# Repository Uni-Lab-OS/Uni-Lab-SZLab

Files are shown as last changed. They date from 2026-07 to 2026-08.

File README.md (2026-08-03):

# Uni-Lab SZLab Poly Studio

SZLab 聚合物工作站领域设备包。仓库根同时是 Python distribution root 和目标
Uni-Lab-OS workspace root；根目录只构建一个 distribution `szlab-poly-studio`，唯一常规
顶层 import package 是 `szlab_poly_studio`。

AI4C 已从本仓库迁出到同级的 `../Uni-Lab-AI4C/`，两边可以独立安装、测试、构建和发布。

## 目录合同

```text
Uni-Lab-SZLab/
├── pyproject.toml
├── szlab_poly_studio/
│   ├── devices/<device_id>/
│   │   ├── device.py
│   │   └── models/
│   ├── resources/
│   ├── workflows/
│   └── common/
├── deployment/
├── tests/
├── docs/
├── scripts/
└── migration/
```

没有 `packages/` 中间层，也没有独立的模型 entry-point 协议。设备、资源和工作流由各自装饰器
定义；模型元数据写在同一个 `@device` 或 `@resource` 上。设备专属资产放在
`devices/<device_id>/models/`，资源专属资产放在 `resources/<resource_id>/models/`，声明中
的 `entry` 相对装饰器所在 Python 文件解析。

当前仓库中的 2.5D 外形已按归属拆成各目录的 `models/shape.yml`。增加 3D 模型时，优先在
同一 `models/` 目录放置一个 Xacro 入口及其 `meshes/` 依赖，并在原装饰器的 `model` 中增加
`format: xacro`、`entry` 和 `macro`。同一 Xacro 默认同时作为 Web、kinematics 和 collision
来源；只有实际存在不同优化产物时才增加用途覆盖。

## 安装、检查和构建

在可运行 Uni-Lab-OS 的 Python 3.11 环境中：

```bash
python -m pip install -e . --no-deps
./scripts/check-package.sh
./scripts/build-package.sh
python -m pytest
```

wheel 输出到 `dist/`。`check-package.sh` 先编译完整 Catalog，再用 `--workspace` 做 OS
只读检查；`build-package.sh` 通过 package manager 构建并审计 clean wheel。设备、资源、工作流和
模型均由 Catalog 发现，Graph 是设备实例、物料拓扑、连接参数和本次激活选择的唯一权威来源。
仓库不再包含运行时 Profile。

Workflow 新代码遵循 Core 的
[`Workflow Python 写法规范`](https://github.com/Uni-Lab-OS/Uni-Lab-Core/blob/main/docs/guides/python-workflow-authoring-standard.md)。当前包含 13 个
Workflow；`s06_material.py` 是 Action 级 `ResourceSlot` 线性链参考实现。

## 本地联调

启动带 FE authoring API 的单进程测试 OS：

```bash
./scripts/start-authoring-os.sh
```

启动真实 runtime OS，或启动固定为测试模式的 OS：

```bash
./scripts/start-runtime-os.sh
./scripts/start-test-os.sh
```

OPC UA 仿真与 Edge 联调可直接使用 5 节点演示工作流
`szlab_poly_studio/workflows/robot_liquid_stirring_demo.py`；对应握手器启动命令见
[`docs/SZLAB_OPCUA_SIM_STARTUP_DEBUG.md`](docs/SZLAB_OPCUA_SIM_STARTUP_DEBUG.md)。

默认图中的直连 PLC 驱动均为 `auto_connect: false`。真机接入前必须单独核验 IP、NodeId、
账号、联锁、急停、物料占用和恢复语义。

SZLab 前端 E2E 截图见 [`docs/E2E_SCREENSHOTS.md`](docs/E2E_SCREENSHOTS.md)，迁移前 12 个历史
工作流的代码与 DAG 截图见
[`docs/ALL_WORKFLOW_SCREENSHOTS.md`](docs/ALL_WORKFLOW_SCREENSHOTS.md)。远端 OPC UA 仿真、
FE-OS 启动和排障命令见
[`docs/SZLAB_OPCUA_SIM_STARTUP_DEBUG.md`](docs/SZLAB_OPCUA_SIM_STARTUP_DEBUG.md)。全部工作流的
真机仿真结果见
[`docs/ALL_WORKFLOWS_LIVE_E2E_20260730.md`](docs/ALL_WORKFLOWS_LIVE_E2E_20260730.md)，动作与 PLC
日志规范见 [`docs/SZLAB_ACTION_LOGGING.md`](docs/SZLAB_ACTION_LOGGING.md)。

## 来源与许可

来源映射见 [`migration/manifest.yaml`](migration/manifest.yaml)，完整来源见 [`NOTICE`](NOTICE)。
上游设备驱动标记为 DP Technology Proprietary License；除非权利人明确授权，本仓库应保持
私有。详见 [`LICENSE`](LICENSE)。

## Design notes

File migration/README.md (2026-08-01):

# 迁移档案

本目录只保存从 `styxhuang/Uni-Lab-OS@d58a8c0` 提取的历史输入与映射证据，不作为运行时
配置源。

- `manifest.yaml` 是 11 个已提交 SZLab local UI preset、6 个 legacy JSON 工作流与当前 Python
  工作流之间的权威映射。
- `legacy/ui-presets`、`legacy/runtime-configs`、`legacy/workflows` 和 `legacy/plc_csv`
  保持原始内容，便于审计，因此可能包含已经失效的本机绝对路径或旧端点。
- 生产包只使用 `szlab_poly_studio/` 下的最新 CSV、Profile、设备实现和 Python 工作流。
- 未在当前工作区或定向浏览器/e2e 持久化位置发现可安全归属到该项目的活动
  `unilabos.workflowDraft`；因此迁移对象以已提交 preset/JSON 为准。

历史动作名 `auto-<method>` 已统一为 `<method>`。这是把工作流写成
`device("<device_id>").<method>(...)` 所必需的语法迁移，不改变相应设备方法。

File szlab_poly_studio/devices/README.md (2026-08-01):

# Device layout

Each device owns one directory named after its stable `@device(id=...)` value. The
driver entry is `device.py`; protocol tables, calibration-independent defaults,
and model assets stay beside it.

```text
devices/<device_id>/
├── device.py
├── models/
│   ├── device.xacro       # add when a 3D model is available
│   ├── meshes/
│   └── shape.yml         # optional 2.5D fallback
└── ...                    # sensors, CSV tables, and helpers
```

Model metadata belongs in the device's `@device(model={...})` declaration. Paths
are relative to `device.py`. A single Xacro entry is the default source for Web,
kinematics, and collision; declare an override only when a genuinely different
optimized asset exists.

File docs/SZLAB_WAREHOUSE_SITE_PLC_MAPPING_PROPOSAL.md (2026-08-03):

# SZLab Warehouse Site 与 PLC 映射确认稿

> 状态：PARTIALLY CONFIRMED / S2 已确认，S071 已按现有证据定案，S3/S11 产品类型仍待确认
> 日期：2026-08-03
> 目的：确认 Warehouse Site、Inventory Site、PLC 在位信号和机器人位置参数之间的映射。

## 1. 核对基线

运行语义基线采用 `origin/main@4682bb3`：

- `szlab_poly_studio/resources/warehouses.py`
- `szlab_poly_studio/resources/carriers/*.py`
- `deployment/graphs/szlab-local-debug.json`
- `szlab_poly_studio/devices/szlab_poly_plc/device.py`
- `szlab_poly_studio/devices/szlab_poly_plc/szlab_plc_0730.csv`

`origin/feat/szlab-material-display@28e6bc9` 的提交时间更新，包含新的 3D 资产和通用
`szlab_poly_beaker_warehouse` 类型，但它没有包含 `origin/main` 最新的启动图和 Workflow
修复。因此当前不存在一个同时包含两边最新内容的已提交分支。本稿使用 `origin/main` 的运行
语义，并交叉检查 material-display 分支的 Warehouse 几何和 Site 数量。

当前工作区的 Warehouse 定义与 `origin/main` 相同；本地启动图的 Warehouse、Site 和 110 个
容器物料与 `origin/main` 数量一致，主要差异是 registry class namespace 和其他设备节点。

### 1.1 启动图库存规模

| Warehouse instance | Site | `occupied_by` | 物料类型 |
|---|---:|---:|---|
| `s1_loading_buffer` | 6 | 6 | TIP box |
| `s2_tip_warehouse` | 6 | 6 | TIP box |
| `s3_unused_beaker` | 36 | 36 | 18×烧杯 + 18×500 mL 样品瓶 |
| `powder_container_warehouse` | 6 | 6 | 粉料容器 |
| `s10_liquid_reagent` | 20 | 20 | 100 mL 试剂瓶 |
| `s11_used_beaker` | 36 | 36 | 18×烧杯 + 18×500 mL 样品瓶 |
| **合计** | **110** | **110** | |

这个 JSON 是“全仓填充”的调试/展示库存。若真机现场不是全仓满载，不得把它原样作为生产
Inventory 初始事实；生产启动图必须按实际库存移除相应 `occupied_by` 和物料节点。

## 2. Site 的权威链路

### 2.1 Warehouse 初始化

Warehouse/ItemizedCarrier 初始化后已经具有：

- `_ordering`：Site label 到 holder 的有序映射；
- `child_locations`：Site 相对坐标；
- `child_size`：Site 尺寸；
- `sites`：当前 holder/occupant；
- `content_type`、`visible` 等序列化属性。

序列化到启动图后，这些信息位于 Warehouse node 的 `config.sites[]`。其中 `label` 是
Warehouse 内稳定的业务键，`occupied_by` 是启动时的逻辑占用关系。

### 2.2 Edge 本地查询

OS 启动后，Graph 只作为一次性输入；运行时权威是同一个可变 `ResourceTreeSet`。
`MaterialGraphCatalog` 把 Warehouse `config.sites[]` 投影为 Material Site：

- Site ID：由 graph identity、Warehouse node ID 和 Site label 确定性生成；
- owner：Warehouse 对应的 Material aggregate；
- occupant：由 `occupied_by` 解析为 Material UUID；
- geometry/content type：来自 Warehouse Site declaration。

前端通过 `GET /api/v1/materials?page=...` 获得 aggregate，现有 FE 会解析
`config.sites` 并展示安装位和占用数。对当前本地启动图实测可查询到 126 个 aggregate，
其中六个 Warehouse 合计 110 个 Site，110 个 Site 均有逻辑 occupant。

### 2.3 Backend Inventory

Backend 已有独立持久化 `Site` 实体，记录：

- `material_uuid`：拥有该 Site 的 Warehouse/Carrier Material；
- `name`、`sort_order`；
- `allowed_resource_template_uuids`；
- `occupied_material_uuid`；
- 几何位置和尺寸。

但当前缺少两段完整链路：

1. Deployment/Warehouse instance 激活时，将 Site declaration 幂等 materialize/upsert 为
   Backend Site rows；
2. 前端一次性查询 Backend 的 flat Site collection。当前 Backend 仅有
   `GET /api/v1/materials/{uuid}/sites`，FE 的 `getGraph()` 只读取 materials，不会逐个补取 Site。

目标链路应为：

```text
Warehouse Site declaration
  -> deployment activation/materialization
  -> Backend Material + Site rows
  -> GET /api/v1/sites（flat collection）
  -> FE 按 material_uuid 归组
```

Edge 本地的 `config.sites` 可保留为兼容投影，但不能成为与 Backend Site 并列的第二套可写
权威。PLC observation 也不能直接改写 `occupied_material_uuid`；它只提供 presence evidence。

## 3. SiteControlBinding 的归属

PLC 地址和机器人程序参数不是 Inventory Site 属性。它们属于 SZLab cell deployment 的
SiteControlBinding，使用 `(warehouse_instance_id, site_label)` 关联 Site declaration，materialize
后再解析到稳定 Site UUID。

每个 binding 至少包含：

```yaml
warehouse_instance_id: s3_unused_beaker
site_label: L1B1
observation:
  provider: szlab_poly_plc
  variable: 传感器状态_上位机[0].NO[6]
interaction:
  product_type: 1
  controller_position_key: 1-1
  controller_position_number: 1
```

运行时必须验证：

- Warehouse 的 Site 集合与 binding Site 集合完全相等或被显式标记为 `inventory_only`；
- 一个 PLC presence variable 只能绑定一个物理 Site；
- 一个 Site 的 sort order、PLC sensor order 和 robot position 是三个独立字段，禁止相互猜算；
- SiteControlBinding 解析为 RobotCommand 后，adapter 不再接收 Site、Material 或 SkillBinding。

## 4. 候选映射

### 4.1 S1 上料过渡仓：暂不绑定机器人/PLC Site

| Site labels | 数量 | 当前证据 | 结论 |
|---|---:|---|---|
| `L1C1..L1C3`, `L2C1..L2C3` | 6 | S01 robot action 只允许 position=1；`[3].NO[6]` 名义上是机械手产品检测，不是六个 Warehouse Site 的在位阵列 | 六个 Site 先标 `inventory_only`，不能猜成 S01 position 1..6 |

如果 S1 设备另有六个在位信号或上料索引表，需要补充现场 PLC 表后再绑定。

### 4.2 S2 TIP 仓：按 JSON Site 顺序映射 1..6（现场已确认）

顺序采用启动图 `config.sites[]` 和 `children[]` 的顺序：从低层到高层，每层从 C1 到 C2。
用户在 2026-08-03 确认该顺序；同时提供的两张 SZLab 3D 现场参考图显示 S2 为三层、每层
两位，图中由下到上分别标注 `T11/T12`、`T21/T22`、`T31/T32`，与启动图一致。

| Site | PLC/robot position | Presence variable |
|---|---:|---|
| `T11` | 1 | `传感器状态_上位机[0].NO[0]` |
| `T12` | 2 | `传感器状态_上位机[0].NO[1]` |
| `T21` | 3 | `传感器状态_上位机[0].NO[2]` |
| `T22` | 4 | `传感器状态_上位机[0].NO[3]` |
| `T31` | 5 | `传感器状态_上位机[0].NO[4]` |
| `T32` | 6 | `传感器状态_上位机[0].NO[5]` |

注意：最新 JSON 将 S2 描述为 3 层×2 位，但当前 `warehouses.py` 仍使用通用的 6×1×1
`warehouse_factory`。Warehouse 初始化实现必须改成与 JSON 和现场确认相同的 3×2 几何和
`T11..T32` label，避免代码初始化与启动图分叉。

本次确认确定了 Site label、层列关系、PLC/robot position 编号及候选 presence variable 的
静态映射。真机启用前仍须逐位放入/取出 TIP 盒，确认 `[0].NO[0..5]` 的实际变化与本表一一
对应；该动作属于映射验收，不再是编号设计决策。

### 4.3 S3 未使用容器仓：高置信度

Site label：

- `L{layer}B{column}`：500 mL 烧杯，`product_type=1`；
- `L{layer}A{column}`：500 mL 样品瓶，候选 `product_type=3`；
- `layer=1..3`，`column=1..6`。

映射规则：

```text
controller_position_key    = "{layer}-{column}"
controller_position_number = (layer - 1) * 6 + column
```

Presence variable：

- B 行按 `S3_UNUSED_BEAKER_SENSORS[controller_position_key]`；
- A 行按 `S3_UNUSED_SAMPLE_VIAL_SENSORS[controller_position_key]`。

边界样例：

| Site | type | key | number | Presence variable |
|---|---:|---|---:|---|
| `L1B1` | 1 | `1-1` | 1 | `[0].NO[6]` |
| `L3B6` | 1 | `3-6` | 18 | `[1].NO[7]` |
| `L1A1` | 3 | `1-1` | 1 | `[1].NO[8]` |
| `L3A6` | 3 | `3-6` | 18 | `[2].NO[9]` |

### 4.4 S071 固体粉桶堆栈机器人接口：位置采用紧凑编号 1..6

S07 在现场语义上应拆成三个概念：

- `powder_container_warehouse`：图中左侧 2 层×3 位的“固体粉桶堆栈”；
- `S071`：机械臂对该六位堆栈执行取/放粉罐时使用的 PLC/机器人子工位编号；
- `S07`：图中右侧带转盘的固体加料设备；其机器人产品交接接口在现有程序中称为 `S072`。

依据是：S071 动作明确叫“取/放粉罐”，读取粉桶堆栈六个 presence sensor，并写入
`S071取放料编号`；独立的 S07 设备动作则负责扫码、旋转到进料位和注粉。用户提供的现场
参考图也把左侧“固体粉桶堆栈”和右侧“S07 固体加料”标成两个物理对象。

Site label `L{layer}C{column}` 与 presence variable 的关系明确：

| Site | key | Presence variable | 采用 position | 当前代码 position |
|---|---|---|---:|---:|
| `L1C1` | `1-1` | `[3].NO[8]` | 1 | 1 |
| `L1C2` | `1-2` | `[3].NO[9]` | 2 | 2 |
| `L1C3` | `1-3` | `[3].NO[10]` | 3 | 3 |
| `L2C1` | `2-1` | `[3].NO[11]` | 4 | 7 |
| `L2C2` | `2-2` | `[3].NO[12]` | 5 | 8 |
| `L2C3` | `2-3` | `[3].NO[13]` | 6 | 9 |

采用值按 2 层×3 位紧凑编号。S07 专用传感器定义本身已经把六个粉桶位明确编号为 1..6；
当前 `robot_S07` 复用了服务于 S3/S11 每层 6 列的 `_slot_number()`，才导致第二层错误发送
7..9。这是跨工位复用编号公式造成的实现缺陷，不应上升为 Warehouse Site 语义。

实现时应由每个 SiteControlBinding 显式保存 `controller_position_number`，S071 不再调用通用
`_slot_number()`。真机启用前仍须以低速/单步模式验证 4、5、6 三个目标点，防止现场机器人
程序另有历史编号；若现场程序确实只接受 7..9，应修订部署 binding，而不是改变 Site label。

### 4.5 S10 试剂瓶仓：高置信度

Site label `R{row}C{column}`，`row=1..4`，`column=1..5`：

```text
controller_position_key    = "{row}-{column}"
controller_position_number = (row - 1) * 5 + column
presence_variable          = S10_LIQUID_REAGENT_SENSORS[key]
```

边界样例：

| Site | key | number | Presence variable |
|---|---|---:|---|
| `R1C1` | `1-1` | 1 | `[4].NO[12]` |
| `R1C5` | `1-5` | 5 | `[5].NO[0]` |
| `R2C1` | `2-1` | 6 | `[5].NO[1]` |
| `R4C5` | `4-5` | 20 | `[5].NO[15]` |

### 4.6 S11 使用后容器仓：高置信度

Site label、product type 和 position 规则与 S3 相同：

- B 行：500 mL 烧杯，`product_type=1`；
- A 行：500 mL 样品瓶，候选 `product_type=3`；
- number：`(layer - 1) * 6 + column`。

Presence variable 改用 S11 的两组：

| Site | type | key | number | Presence variable |
|---|---:|---|---:|---|
| `L1B1` | 1 | `1-1` | 1 | `[6].NO[0]` |
| `L3B6` | 1 | `3-6` | 18 | `[7].NO[1]` |
| `L1A1` | 3 | `1-1` | 1 | `[7].NO[2]` |
| `L3A6` | 3 | `3-6` | 18 | `[8].NO[3]` |

## 5. 映射覆盖结论

| 分类 | Site 数量 |
|---|---:|
| 已确认静态映射：S2 | 6 |
| 证据收敛后定案、待真机逐点验收：S071 | 6 |
| 高置信度 PLC binding：S3 + S10 + S11 | 92 |
| 无六位现场证据、暂定 inventory-only：S1 | 6 |
| **总计** | **110** |

候选配置可为 104 个 Site 生成互不重复的 PLC presence variable；S1 六个 Site 不生成
SiteControlBinding。

## 6. 确认后实施顺序

1. 将 material-display 的通用 beaker Warehouse/3D 资产合并到最新 main，生成一个真正统一的
   基线提交。
2. 修正 S2 Warehouse factory，使初始化结果、测试和 JSON 都是 `T11..T32`、3 层×2 位。
3. 新增 deployment-owned SiteControlBinding catalog；启动时与实际 Warehouse Site 集合做
   exact-set validation，缺项、重项或未知 Site 均拒绝启用机器人动作。
4. PLC stack observer 按 Site binding 重排 raw variables，向 OS 发布 Warehouse Site order 的
   observation array；传感器只提供 presence evidence。
5. Material Handling resolver 使用 Site UUID 查 binding，解析 Site Action 为 RobotCommand；
   PLC adapter 只接收 RobotCommand。
6. 增加 deployment Site materialization/upsert；Backend 提供 flat Site read collection，FE 一次
   查询并按 `material_uuid` 归组。
7. 保留两份启动数据：全仓 110 物料的 debug/display fixture，以及按现场真实占用生成的
   production inventory graph。

## 7. 现场确认状态

1. **已确认**：S2 的位置 1..6 依次对应 `T11,T12,T21,T22,T31,T32`。
2. **已按证据定案，待真机逐点验收**：S071 是固体粉桶堆栈的机器人接口，第二层采用紧凑
   编号 `4,5,6`；当前代码的 `7,8,9` 来自错误复用每层六列公式。
3. S3/S11 的 500 mL 样品瓶在机器人程序中是否确认为 `product_type=3`？

S2 可进入代码修正和逐位传感器验收；S071 可按 1..6 实现，但在逐点验收前不得开放自动
流程；S3/S11 的 product type 在确认前不接入真机执行路径。

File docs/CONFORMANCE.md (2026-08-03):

# SZLab 领域设备包一致性合同

## 仓库边界

- 仓库根是唯一 Python distribution root 和目标 OS workspace root；
- 根 `pyproject.toml` 的 distribution 是 `szlab-poly-studio`；
- 唯一常规顶层 import package 是 `szlab_poly_studio`；
- 不允许 `packages/` 中间层或第二个领域 import package；
- AI4C 由独立的同级仓库维护。

## 发现边界

- 顶层定义只来自 `@device`、`@resource`、`@workflow_definition`；
- 动作、状态和订阅装饰器归入所属设备；
- 模型由同一个设备/资源装饰器绑定；
- `deployment/`、`tests/`、`docs/`、`migration/` 不属于扫描根；
- 静态发现不得 import 驱动、实例化设备或连接硬件。
- Graph 是实例拓扑、连接参数与激活选择的唯一权威来源，不使用运行时 Profile。

## Workflow authoring 边界

- 新 Workflow 遵循 Core 的
  [`Workflow Python 写法规范`](https://github.com/Uni-Lab-OS/Uni-Lab-Core/blob/main/docs/guides/python-workflow-authoring-standard.md)；
- 新材料链必须从 Action 参数起使用 `ResourceSlot`，不能只靠 position/sample_id 和控制边推断；
- `szlab_poly_studio/workflows/s06_material.py` 是当前可发布的单工作流参考实现；
- `docs/examples/workflow_authoring/*_target.py` 只描述 C1 目标合同，不进入 `package.yaml`。

## 资产边界

- 设备资产位于 `devices/<device_id>/models/`；
- 资源资产位于 `resources/<resource_id>/models/`；
- 模型入口相对声明 Python 文件解析，并且必须位于 import package 内；
- wheel 必须携带 YAML、Xacro、URDF、mesh 和 texture 等完整依赖闭包；
- 运行日志、数据库、现场标定和凭据不得进入 wheel。

## 本地检查

```bash
python -m pip install -e . --no-deps
./scripts/check-package.sh
python -m pytest
./scripts/build-package.sh
```

`check-package.sh` 执行 `package inspect --path .` 与 `--workspace . --check_mode`；
`build-package.sh` 通过 package manager 构建并审计 clean wheel。自动测试同时验证 workspace /
clean-wheel Catalog 一致性。

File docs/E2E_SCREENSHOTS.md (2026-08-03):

# SZLab 最新前端 E2E 截图

本页聚焦 SZLab 物料视图和一个代表性工作流。全部 12 个生产工作流截图见
[`ALL_WORKFLOW_SCREENSHOTS.md`](ALL_WORKFLOW_SCREENSHOTS.md)。

截图由 `uni-lab-fe@d734337f63da832c11d704013be0d80f98681116`、
`deployment/graphs/szlab-local-debug.json` 和 FE-OS migration 后的单进程 OS 共同生成。浏览器视口为
1920×1200；当前复现流程通过 workspace Catalog 读取领域定义。

## Python 代码与节点画布

S04 机械臂—磁搅流程通过真实 `/api/v1/authoring/compile` 和
`/api/v1/workflows:validate` 接口，画布断言为 3 个节点、2 条控制边。

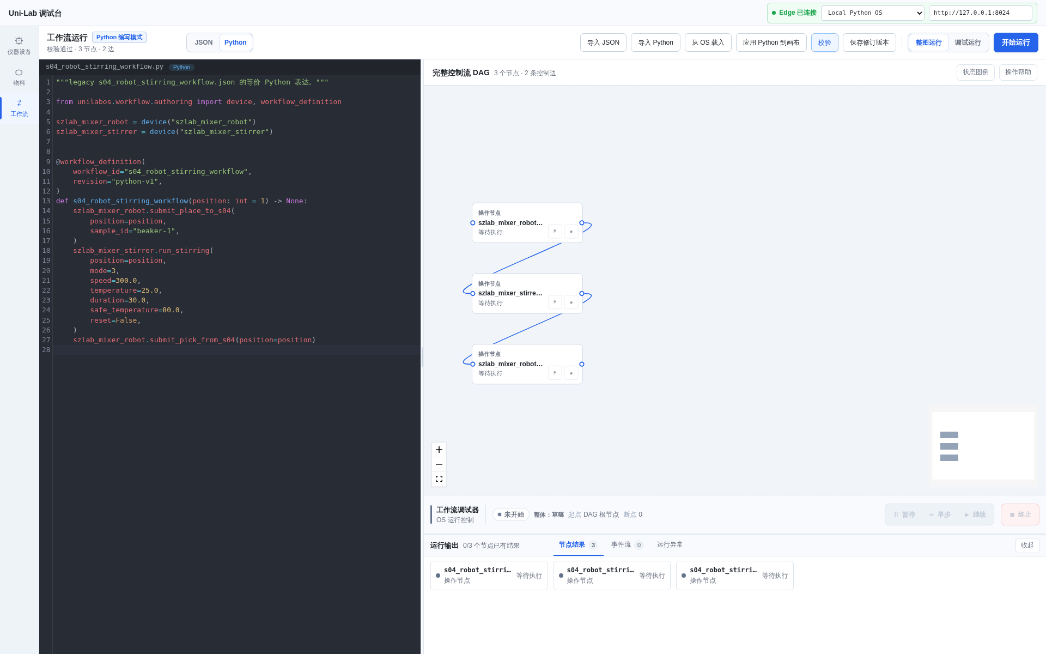
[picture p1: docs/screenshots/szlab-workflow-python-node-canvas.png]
SZLab Python 工作流与节点画布


## 2D 物料界面

2D 投影从 `/api/v1/materials` 加载 22 个 SZLab 聚合对象，不包含 AI4C 设备。

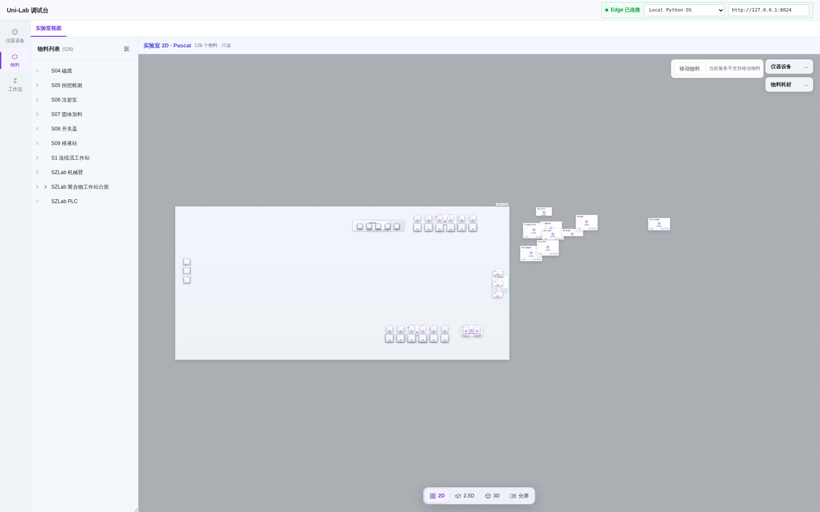
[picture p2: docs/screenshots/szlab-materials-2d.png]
SZLab 2D 物料界面


## 2.5D 物料界面

2.5D SVG 投影使用同一份 22 对象 Material Aggregate；截图选中了
`debug_beaker_500ml`，右侧 Inspector 展示其配置、世界坐标和 revision。

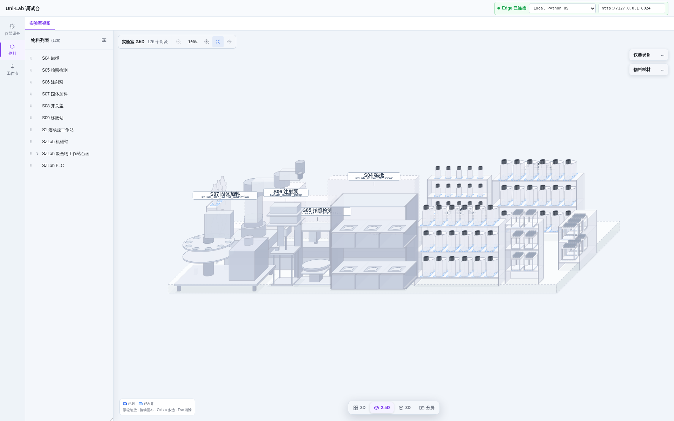
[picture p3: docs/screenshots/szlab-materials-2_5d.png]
SZLab 2.5D 物料界面


## 复现

先分别启动 SZLab 测试 OS 与最新前端：

```bash
UNILAB_PYTHON=/home/changjunhan/.micromamba/envs/unilab/bin/python \
  ./scripts/start-authoring-os.sh

cd ../uni-lab-fe
pnpm --filter @unilab/kernel-web preview --host 127.0.0.1 --port 4173
```

再从本仓库运行：

```bash
./scripts/capture-szlab-e2e.sh
```

机器可读结果保存在
[`screenshots/szlab-e2e-result.json`](screenshots/szlab-e2e-result.json)。
E2E 请求中的工作流编译、编写校验、Canonical 校验和 Material API 均为 200，未出现未预期的
浏览器错误。结果文件中旧设备页端点的历史兼容性警告不参与工作流与物料界面的通过判定。

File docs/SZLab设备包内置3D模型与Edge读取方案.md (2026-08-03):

# SZLab 设备包内置 3D 模型与 Edge 读取方案

## 结论

SZLab 模型应直接放在对应驱动目录的 `models/` 下，并由该驱动的 `@device(model=...)` 声明。
资源模型采用相同原则，放在 `resources/<resource_id>/models/` 并由 `@resource` 声明。仓库中
不再存在包级模型 provider 或总清单。

## 当前已落地结构

```text
szlab_poly_studio/
├── devices/
│   ├── szlab_mixer_robot/
│   │   ├── device.py
│   │   ├── robot_S01.py ... robot_S11.py
│   │   └── models/shape.yml
│   ├── szlab_mixer_pump/
│   │   ├── device.py
│   │   ├── sensors.py
│   │   ├── pump_nodes.csv
│   │   └── models/shape.yml
│   ├── szlab_mixer_stirrer/models/shape.yml
│   ├── szlab_mixer_photoshotting/models/shape.yml
│   └── szlab_s07_solid_addition/models/shape.yml
└── resources/
    ├── materials.py
    ├── warehouses.py
    └── <resource_id>/models/shape.yml
```

原全局 2.5D 外形数据已经无损拆到上述归属目录。每个资产由相应装饰器直接引用。仓库当前
没有提交真实 Xacro/mesh/GLB，所以不能声称 3D 闭环已完成；现在完成的是目录、绑定和打包
合同，以及已有 2.5D 资产的迁移。文件使用 `.yml` 是为了避开当前 OS 将设备子树内
`*.yaml` 误当旧式注册表的兼容缺陷；内容仍是标准 YAML，实际定位以装饰器 `entry` 为准。

## 机械臂加入真实 3D 模型后的目录

```text
szlab_poly_studio/devices/szlab_mixer_robot/
├── device.py
└── models/
    ├── device.xacro
    ├── meshes/
    │   ├── rail.stl
    │   ├── base.stl
    │   └── arm.dae
    ├── textures/
    ├── config/
    └── shape.yml
```

`device.py` 中的目标声明：

```python
@device(
    id="szlab_mixer_robot",
    display_name="SZLab Mixer 机器人任务",
    category=["robotic_arm"],
    model={
        "format": "xacro",
        "entry": "models/device.xacro",
        "macro": "szlab_mixer_robot",
        "shape": {
            "format": "unilab.shape/v1",
            "entry": "models/shape.yml",
        },
    },
)
class SzlabMixerRobotDevice:
    ...
```

一个 Xacro 就是默认的完整表示，不需要为 Web、kinematics 和 collision 重复三次。只有 Web
实际使用独立轻量 GLB，或 collision 使用独立简化体时，才写 `overrides`。

## `mesh_path` 的作用

`mesh_path` 很有用，但它是运行时注入的资产根，不是打包前替换的文本变量：

```xml
<xacro:macro name="szlab_mixer_robot" params="mesh_path prefix:=''">
  <link name="${prefix}rail">
    <visual>
      <geometry>
        <mesh filename="${mesh_path}/meshes/rail.stl"/>
      </geometry>
    </visual>
  </link>
</xacro:macro>
```

Edge 根据 Catalog 里的声明文件位置，把
`.../szlab_mixer_robot/models` 注入 `mesh_path`。这样 workspace、wheel 和缓存包只改变注入值，
Xacro 源文件完全相同。Web 获得的是 Edge 生成的资产 URL，不是这条服务器路径。

## Edge 目标读取方法

1. `unilab --workspace .` 读取根 `pyproject.toml`；
2. 定位唯一 import package `szlab_poly_studio`；
3. AST 递归扫描 `@device/@resource/@workflow_definition`；
4. 对每个模型按声明 Python 文件解析相对 `entry`；
5. 校验入口、include、mesh、texture、路径 containment 和 wheel package-data；
6. 把定义及资产闭包写进同一个 PackageCatalog；
7. Graph 选择设备后才 import 驱动；
8. 前端请求模型时，Edge 通过 Catalog 返回元数据和受控资产 URL；
9. Xacro consumer 以已校验模型目录作为 `mesh_path`。

发现模型不等于实例化设备，也不等于连接 PLC。AST 扫描和资产校验必须保持无副作用。

## 当前与目标的差距

SZLab 已完成根单包、驱动归位、外形共置、装饰器绑定和 package-data；OS 已提供
PackageCatalogCompiler、`--workspace`、资产 Source Adapter 和 Shape 资产读取。真实 3D
Edge/Web 闭环仍需等第一套真实 Xacro/mesh 到位后验收。

## 第一套真实模型建议

优先选择 `szlab_mixer_robot` 做垂直闭环，因为它同时覆盖 Xacro、mesh、关节、碰撞、
`mesh_path` 和 Web：

1. 提交可再分发的 Xacro 与 mesh；
2. 补充装饰器的 `format/entry/macro`；
3. 从 clean wheel 编译 Catalog；
4. 比较 workspace 与 wheel Catalog；
5. 启动 Edge，验证模型资产 URL；
6. 验证 Web、kinematics、collision 都来自同一默认 Xacro；
7. 再评估是否真的需要独立 Web GLB 或 collision override。

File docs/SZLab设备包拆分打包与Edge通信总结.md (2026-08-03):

# SZLab 设备包拆分、打包与 Edge 通信总结

## 1. 一般设备如何从 Uni-Lab-OS 分离为领域设备包

### 1.1 先确定边界

设备包应拥有设备驱动、动作、资源定义、工作流、协议表和模型资产；Uni-Lab-OS
保留通用装饰器、Registry、调度、通信抽象、PackageCatalog 编译和运行时。拆分时禁止把 OS
内部任意模块整段复制进设备包，只有确实属于领域设备且无法复用的适配器才进入 `common/`。

### 1.2 建立根单包仓库

```text
repository root = Python distribution root = OS workspace root
```

根 `pyproject.toml` 直接构建唯一 import package。SZLab 使用：

```text
distribution: szlab-poly-studio
import package: szlab_poly_studio
class namespace: community.szlab_poly_studio
```

一个包可以定义多个设备；设备身份来自各自的 `@device(id=...)`，不是来自 distribution 名。

### 1.3 迁移步骤

1. 将驱动类迁到 `devices/<device_id>/device.py`；
2. 保留 `@device`、`@action`、`@topic_config`、`@subscribe` 等装饰器；
3. 将资源工厂迁到 `resources/` 并保留 `@resource`；
4. 将 Python 工作流迁到 `workflows/` 并保留 `@workflow_definition`；
5. 将 CSV、JSON、Xacro、mesh、texture 放到拥有者目录；
6. 去除 OS 私有绝对 import、硬编码本机路径、凭据和运行数据；
7. 配置 package-data，构建 clean wheel 并验证静态发现结果；
8. 在 Graph 中写入实例拓扑和连接参数；只有 Graph 选中设备后，运行时才允许 import 和连接硬件。

AI4C 已作为同级 `Uni-Lab-AI4C/` 独立根单包，不再和 SZLab 组成 monorepo。

## 2. 设备包目录与包含的信息

SZLab 当前结构：

```text
Uni-Lab-SZLab/
├── pyproject.toml                 # distribution 身份、依赖、package-data
├── szlab_poly_studio/
│   ├── devices/<device_id>/
│   │   ├── device.py              # @device 与动作
│   │   ├── sensors.py             # 可选协议语义
│   │   ├── *.csv / *.json         # 协议表、静态参数
│   │   └── models/                # 设备专属模型闭包
│   ├── resources/                 # @resource、warehouse、deck、资源模型
│   ├── workflows/                 # @workflow_definition
│   ├── common/                    # 本包内部共享实现
│   └── __init__.py
├── deployment/graphs/             # 实例图；不属于装饰器扫描根
├── tests/                          # Catalog、Graph、工作流、资产和 wheel 测试
├── scripts/                        # build/check/start 辅助入口
├── docs/
└── migration/                      # 可审计历史输入，不参与运行时发现
```

不同层次的信息含义：

- `@device/@resource/@workflow_definition`：稳定类型身份和静态能力；
- 从属装饰器：设备的动作、状态、订阅和调度属性；
- Graph：本次部署的实例 ID、位置、连接参数和选择结果；
- `models/`：随设备/资源类型发布的可移植模型，不保存现场标定；
- runtime：日志、数据库、缓存，不进入 wheel 和 Git。

## 3. 设备包如何与 Uni-Lab-OS Edge 通信

### 3.1 发现与运行分离

目标启动方式：

```bash
unilab --workspace . -g deployment/graphs/szlab-local-debug.json
```

OS 读取根 `pyproject.toml`，AST 扫描唯一 import package，编译统一 PackageCatalog。这个阶段不
import 驱动、不实例化设备、不连接 PLC。Graph 选择本次运行需要的实例；选中后才加载对应
Python 类。

仓库检查入口为：

```bash
python -m unilabos.app.main package inspect --path .
unilab --workspace . --check_mode
```

2.5D 模型使用显式绑定的 `models/shape.yml`，避免兼容加载器把设备子树内的 `*.yaml`
误判成旧注册表。目录已经符合 workspace 合同，但不能把兼容命令当成最终 package manager。

### 3.2 Edge 内的通信层次

```text
设备包装饰器/驱动
        │
        ▼
Registry + PackageCatalog
        │
        ├── ROS device action / topic / subscription
        ├── local bridge authoring/runtime API
        └── Edge asset API（模型）
        │
        ▼
PLC / HTTP 设备 / 前端 / 调度器
```

SZLab 的 PLC 结构是“一条实际 PLC 连接 + 多个业务设备”：

- `szlab_poly_plc` 拥有 OPC UA 连接和通用读写动作；
- robot、S04-S09 等业务设备通过 `PLCActionGateway` 调用 PLC 设备动作；
- 业务设备不各自建立第二条 OPC UA 连接；
- Graph 中用 `plc_device_id: szlab_poly_plc` 绑定实例；
- 测试图默认 `auto_connect: false`。

### 3.3 工作流与 Graph

Python 工作流通过 `device("instance_id").action(...)` 描述调用，由 OS AST 编译成 Canonical
workflow；不使用 `eval/exec`。工作流声明随 Catalog 交付，Graph 决定具体实例、拓扑与连接
参数；local bridge 与 Edge 消费同一份 PackageCatalog，不维护另一套扫描器。

### 3.4 模型通信

模型通过 `@device/@resource(model=...)` 进入 Catalog。Edge 根据声明文件解析相对路径、校验
资产闭包并返回受控 URL；Xacro 的 `mesh_path` 由 Edge 注入。详细规范见
[`设备包3D模型存储规范.md`](设备包3D模型存储规范.md)。

## 4. 验证命令

```bash
python -m pip install -e . --no-deps
./scripts/check-package.sh
python -m pytest
./scripts/build-package.sh
```

验收至少覆盖：唯一根包、Catalog 发现数量、Graph 引用闭合、工作流编译、模型相对路径、wheel
资产闭包、workspace/clean-wheel Catalog 一致、无跨包 import、默认不连硬件。

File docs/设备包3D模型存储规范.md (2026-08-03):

# Uni-Lab 领域设备包 3D 模型存储规范

## 1. 目标与适用范围

本规范定义设备或资源的 3D/2.5D 模型如何随领域设备包一起安装、发现、校验和读取。目标是：

- 引用一个设备包时，同时获得驱动、动作、资源、工作流和模型；
- workspace、editable install、wheel 和远端缓存包使用同一套相对路径语义；
- 模型身份只绑定在 `@device` 或 `@resource`，不再维护包级第二份发现协议；
- 设备专属资产与驱动共同演进，移动设备目录时能整体迁移；
- 未选中的设备可以被静态发现，但不会因此实例化、连接硬件或执行 Xacro。

本文中的“必须”“禁止”“推荐”分别表示规范性要求、不可接受做法和默认选择。

## 2. 仓库与 Python 包边界

领域仓库根必须同时是 Python distribution root 和 OS workspace root：

```text
Uni-Lab-SZLab/
├── pyproject.toml
├── szlab_poly_studio/              # 唯一顶层 import package
│   ├── devices/
│   ├── resources/
│   ├── workflows/
│   └── common/
├── deployment/
├── tests/
├── docs/
├── scripts/
└── migration/
```

禁止增加 `packages/` 中间层。一个 import package 可以包含任意多个设备、资源和工作流；
“一个 distribution”不等于“一个设备”。

## 3. 资产放置位置

### 3.1 设备专属模型

```text
<import_package>/devices/<device_id>/
├── device.py
├── models/
│   ├── device.xacro
│   ├── meshes/
│   │   ├── base.stl
│   │   └── arm.dae
│   ├── textures/
│   ├── config/
│   └── shape.yml
└── ...
```

`<device_id>` 必须与 `@device(id="...")` 的稳定机器 ID 一致。设备模型禁止放到仓库根的共享
`models/`，也不应塞进 `scripts/`、`deployment/` 或运行时数据目录。

### 3.2 资源专属模型

```text
<import_package>/resources/<resource_id>/models/
├── resource.xacro
├── meshes/
├── textures/
└── shape.yml
```

资源 ID 必须与 `@resource(id="...")` 一致。两个资源确实使用同一几何时，可以在构建阶段从
一个明确的源生成两份闭包，或者等待 Catalog schema 提供受控的包内共享引用；禁止使用逃出
Python 包根的 `../../..` 路径。

## 4. 装饰器是唯一模型绑定点

### 4.1 Xacro 默认写法

```python
@device(
    id="szlab_mixer_robot",
    display_name="SZLab 搬运机械臂",
    category=["robotic_arm", "material_transport"],
    model={
        "format": "xacro",
        "entry": "models/device.xacro",
        "macro": "szlab_mixer_robot",
    },
)
class SzlabMixerRobotDevice:
    ...
```

`entry` 相对声明该装饰器的 `device.py` 解析，而不是相对进程当前目录、仓库根或 OS 安装目录。

当 `format == "xacro"` 时，这一个入口默认同时表达：

- Web 可视化的几何与关节树；
- kinematics 使用的 link/joint 结构；
- collision 使用的碰撞几何。

因此禁止为了形式完整，把同一个 Xacro 重复写成三份 `web/kinematics/collision` 配置。只有
确实生成了不同资产时才增加覆盖，例如 Web 使用轻量 GLB、碰撞使用凸包 URDF：

```python
model={
    "format": "xacro",
    "entry": "models/device.xacro",
    "macro": "szlab_mixer_robot",
    "overrides": {
        "web": {"format": "glb", "entry": "models/web/device.glb"},
        "collision": {"format": "urdf", "entry": "models/collision/device.urdf"},
    },
}
```

### 4.2 2.5D 外形

没有真实 3D 模型时，可以绑定轻量外形作为前端回退：

```python
model={
    "shape": {
        "format": "unilab.shape/v1",
        "entry": "models/shape.yml",
    },
}
```

之后加入 Xacro 时，在同一个 `model` 字典增加 `format/entry/macro`，保留 `shape` 作为低带宽
或加载失败时的回退。不要恢复全包外形清单。

本规范把轻量外形文件统一命名为 `shape.yml`。`.yml` 是标准 YAML，模型由装饰器中的显式
`entry` 定位，不依赖扩展名发现。Catalog 同时接受 `.yml` 和 `.yaml`，但包内应保持一种命名，
避免无意义的格式分叉。

## 5. Xacro 与 `mesh_path`

推荐继续使用 Xacro，尤其是有关节、宏参数、多个 mesh、碰撞体或 MoveIt 配置的设备。静态、
无关节且只服务浏览器的资源可以直接用 GLB；简单刚体也可用 URDF。

Xacro 中可以保留 `mesh_path` 参数：

```xml
<xacro:macro name="szlab_mixer_robot" params="mesh_path prefix:=''">
  <mesh filename="${mesh_path}/meshes/base.stl"/>
</xacro:macro>
```

但 `mesh_path` 的值必须由 Edge 的资产 Source Adapter 注入：

- workspace：注入 `device.py` 同级的 `models/` 绝对路径；
- installed distribution：通过 `importlib.resources` 定位 wheel 中的 `models/`；
- cached archive：注入校验、解包后的只读缓存资产根；
- Web：Edge 返回受控资产 URL 根，不向浏览器泄露服务器绝对路径。

用户不需要手改 Xacro 的本机绝对路径，也不需要在打包前批量替换路径。构建脚本只负责校验
闭包和生成 Catalog，不应重写源文件。

## 6. 模型目录应包含什么

按需包含：

- 主入口：`device.xacro`、`resource.xacro`、`.urdf` 或 `.glb`；
- 几何：STL、DAE、OBJ/MTL、GLTF/GLB；
- 贴图：PNG/JPEG 等；
- 运动学/控制配置：仅在设备确实需要时放入 `config/`；
- 2.5D 回退：`shape.yml`；
- 资产许可证和来源说明：第三方 CAD/mesh 必须可追溯。

生产示教点、现场标定结果、密钥、IP、操作者和运行日志禁止进入通用 wheel。机器人点位合同可
随包，现场 pose 与 calibration revision 应由部署侧权威存储维护。

## 7. 打包要求

`pyproject.toml` 必须包含所有资产类型：

```toml
[tool.setuptools.package-data]
szlab_poly_studio = [
  "**/*.yaml", "**/*.yml", "**/*.xacro", "**/*.urdf",
  "**/*.stl", "**/*.dae", "**/*.obj", "**/*.mtl",
  "**/*.gltf", "**/*.glb", "**/*.png", "**/*.jpg", "**/*.jpeg",
]
```

构建检查必须在干净 wheel 中验证：

1. 每个装饰器 `model.entry` 是静态字符串；
2. 路径相对声明文件解析并位于 import package 内；
3. 入口和它引用的 include、mesh、texture 均存在；
4. symlink 不逃出资产根；
5. wheel 安装后仍能得到同一个资产闭包；
6. workspace Catalog 与 clean-wheel Catalog 一致。

## 8. Edge 读取流程

目标 OS 的读取链路是：

```text
workspace / installed wheel / cached archive
                │
                ▼
        PackageCatalogCompiler
        ├── AST 读取装饰器元数据
        ├── 解析声明文件位置
        ├── 校验 model.entry 与资产闭包
        └── 生成统一 PackageCatalog
                │
        ┌───────┴────────┐
        ▼                ▼
  Registry/Runtime   Edge asset API
                          │
                          ▼
                     Web / Xacro consumer
```

发现阶段只读 AST 和静态资产，不 import 驱动、不执行 Xacro、不实例化设备。Graph 选中
某个设备后，运行时才允许 import 驱动；Web 请求模型时，Edge 再通过 Catalog 中的声明位置读取
已校验资产。

## 9. 安全与版本规则

- 拒绝绝对路径、路径逃逸和资产根外 symlink；
- 不根据设备名称猜文件路径；
- 不允许浏览器直接读取服务器文件系统；
- 模型变化随 distribution 版本发布，Catalog 记录版本和 digest；
- 超大 CAD 源文件是否进包由许可证和体积策略决定，运行必需的派生资产必须进入 wheel；
- 模型解析失败应产生明确诊断，不得静默连接硬件或使用错误设备模型。

## 10. 提交检查清单

- [ ] 模型位于对应设备/资源的 `models/`；
- [ ] `@device/@resource` 直接绑定模型；
- [ ] Xacro 只声明一次默认入口；
- [ ] `mesh_path` 由 Edge 注入，无本机绝对路径；
- [ ] package-data 覆盖完整资产类型；
- [ ] workspace 与 wheel 中的相对路径一致；
- [ ] 未携带现场点位、密钥或运行数据；
- [ ] 许可证和来源可追溯；
- [ ] 不存在包级第二套模型发现配置。

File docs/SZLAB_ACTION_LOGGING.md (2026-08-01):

# SZLab 动作与 PLC 等待日志

SZLab 设备动作默认在 Edge 日志中输出结构化、可检索的调试信息。该功能只修改
Uni-Lab-SZLab 设备包，不修改 Uni-Lab-OS。

## 日志标记

| 标记 | 内容 |
| --- | --- |
| `SZLAB-ACTION` | 每个 `@action` 的动作名称、输入参数、耗时、结果或失败原因 |
| `SZLAB-STEP` | 设备内部业务步骤，例如等待烧杯、允许加工、机器人握手或参数清零 |
| `SZLAB-PLC-CALL` | 业务设备通过唯一 `szlab_poly_plc` 发起的跨设备调用 |
| `SZLAB-PLC-WAIT` | 等待变量、期望值、实际值变化、持续等待、成功或超时 |
| `SZLAB-PLC-WRITE` | 写入变量、值、NodeId、尝试次数、耗时和失败异常 |
| `SZLAB-PLC-READ` | 读取失败及其异常；成功读取仅在 DEBUG 级别记录，避免属性轮询刷屏 |
| `SZLAB-HTTP` | S1 HTTP 动作等待的接口、超时、响应状态和网络异常 |

密码、Token、Secret、Authorization 等字段会显示为 `***`。长列表和字典会截断，
防止单条日志过大。

## 示例

```text
[SZLAB-ACTION] START trace=38a55f16b2 action=SzlabMixerPumpDevice.run_solvent_addition params={'pump': 1, 'volume': 8, ...}
[SZLAB-STEP] WAIT trace=38a55f16b2 action=SzlabMixerPumpDevice.run_solvent_addition description=等待 S06 允许加工 variable=S06允许加工 expected=True timeout=300.000s
[SZLAB-PLC-CALL] START trace=38a55f16b2 action=SzlabMixerPumpDevice.run_solvent_addition plc_device=szlab_poly_plc operation=wait_variable_equal ...
[SZLAB-PLC-WAIT] OBSERVED trace=- action=- variable=S06允许加工 node_id=ns=4;s=上位机通讯|S06允许加工 expected=True actual=False elapsed=0.081s
[SZLAB-PLC-WAIT] SUCCESS trace=- action=- variable=S06允许加工 node_id=ns=4;s=上位机通讯|S06允许加工 expected=True actual=True elapsed=5.132s
[SZLAB-PLC-WRITE] START trace=- action=- variable=S06工艺选择 node_id=ns=4;s=上位机通讯|S06工艺选择 value=1 attempts=3
[SZLAB-PLC-WRITE] SUCCESS trace=- action=- variable=S06工艺选择 node_id=ns=4;s=上位机通讯|S06工艺选择 value=1 attempt=1/3 elapsed=0.047s
[SZLAB-ACTION] SUCCESS trace=38a55f16b2 action=SzlabMixerPumpDevice.run_solvent_addition elapsed=18.245s result='S06 泵 1 加液流程完成'
```

如果等待失败，会包含最后一次实际值：

```text
[SZLAB-PLC-WAIT] TIMEOUT ... variable=S06加工完成 expected=True last_actual=False elapsed=300.041s
[SZLAB-ACTION] FAIL ... reason='S06 加工完成等待超时'
```

如果写入失败，会包含变量、写入值、NodeId、重试次数和原始异常：

```text
[SZLAB-PLC-WRITE] FAIL ... variable=S06参数写入完成 ... value=True attempt=3/3 cause=TimeoutError: timed out
```

`trace` 用于关联同一业务动作的 `SZLAB-ACTION`、`SZLAB-STEP` 和
`SZLAB-PLC-CALL`。统一 PLC 设备在独立 ROS 执行线程中处理实际 OPC UA 请求，因此底层
`SZLAB-PLC-WAIT/WRITE/READ` 可能显示 `trace=-`；此时按变量名、操作名和相邻时间定位。

## 实时查看

后台启动 Edge 时：

```bash
cd /home/changjunhan/Uni-Lab-Core/Uni-Lab-SZLab

tail -f runtime/ideawit-e2e/logs/edge.log \
  | rg --line-buffered 'SZLAB-(ACTION|STEP|PLC-CALL|PLC-WAIT|PLC-WRITE|PLC-READ|HTTP)'
```

查看某次动作的完整链路：

```bash
rg 'trace=38a55f16b2|S06加工完成|S06工艺选择' \
  runtime/ideawit-e2e/logs/edge.log
```

只看失败：

```bash
rg 'SZLAB-.*(FAIL|TIMEOUT|ERROR)' \
  runtime/ideawit-e2e/logs/edge.log
```

交互式启动 Edge 时这些日志会同时直接显示在终端。

## 等待日志频率

等待开始时打印一次；实际值变化时打印一次；值没有变化时每 10 秒打印一次
`STILL`；成功或超时时再打印一次。普通成功读取保持 DEBUG 级别，心跳写入也保持
DEBUG 级别，避免掩盖真正的动作日志。

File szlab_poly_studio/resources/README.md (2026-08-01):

# Resource layout

Resource factories live in this package and bind their assets directly through
`@resource(model={...})`. Resource-owned files use the stable resource ID:

```text
resources/<resource_id>/models/
├── resource.xacro         # add when a 3D model is available
├── meshes/
└── shape.yml             # optional 2.5D fallback
```

Model paths are relative to the Python file containing the decorator. There is no
package-wide model provider or model manifest.

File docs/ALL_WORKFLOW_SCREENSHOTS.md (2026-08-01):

# 全部生产工作流 E2E 截图

总计 12 个 SZLab 生产 Python 工作流。每个工作流都经过：

1. Python 源码直接提交 `/api/v1/authoring/compile`；
2. 最新 `uni-lab-fe` Python 编辑器重新载入源码；
3. 点击“编译 Python”；
4. 点击“校验”并通过 `/api/v1/workflows:validate`；
5. 核对真实节点数与控制边数后截取代码和完整 DAG。

机器可读结果见
[`screenshots/all-workflows-e2e-result.json`](screenshots/all-workflows-e2e-result.json)。

## SZLab

### 1. S04 磁搅单工位

`szlab_magnetic_stirring_workflow`：1 节点、0 边。

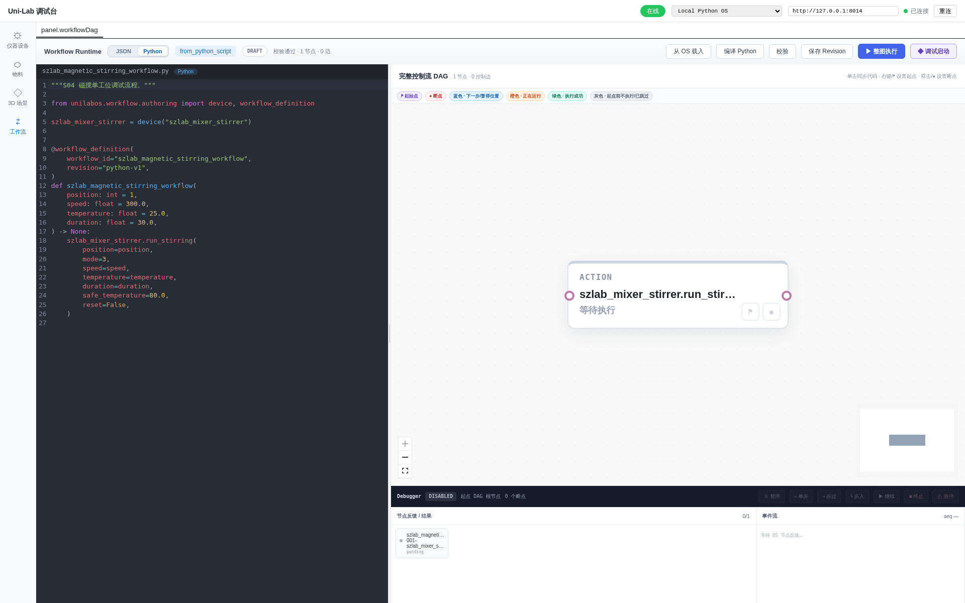
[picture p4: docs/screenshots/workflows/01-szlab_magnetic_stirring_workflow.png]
S04 磁搅单工位


### 2. S05 拍照检测

`szlab_photoshotting_workflow`：1 节点、0 边。

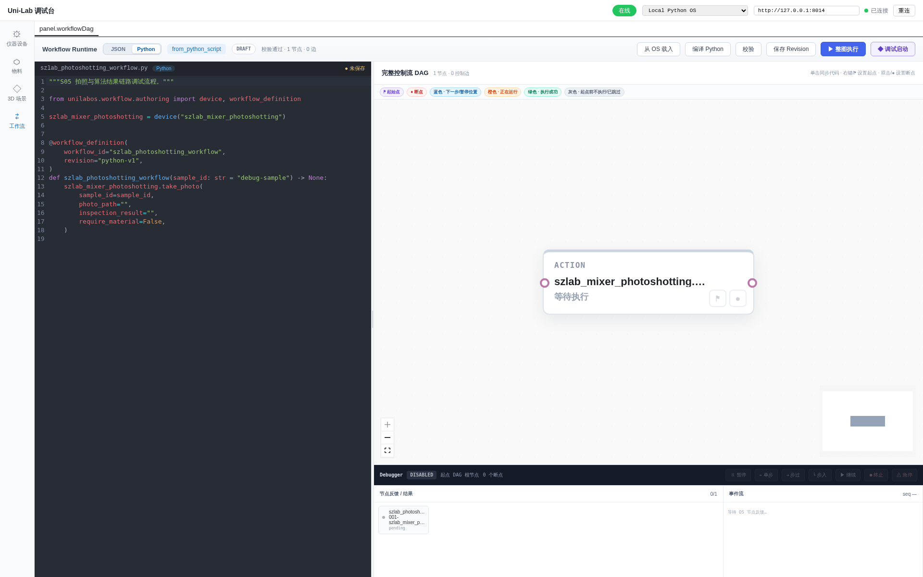
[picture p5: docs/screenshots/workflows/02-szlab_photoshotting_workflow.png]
S05 拍照检测


### 3. 机械臂 S04 取放

`szlab_robot_action_workflow`：2 节点、1 边。

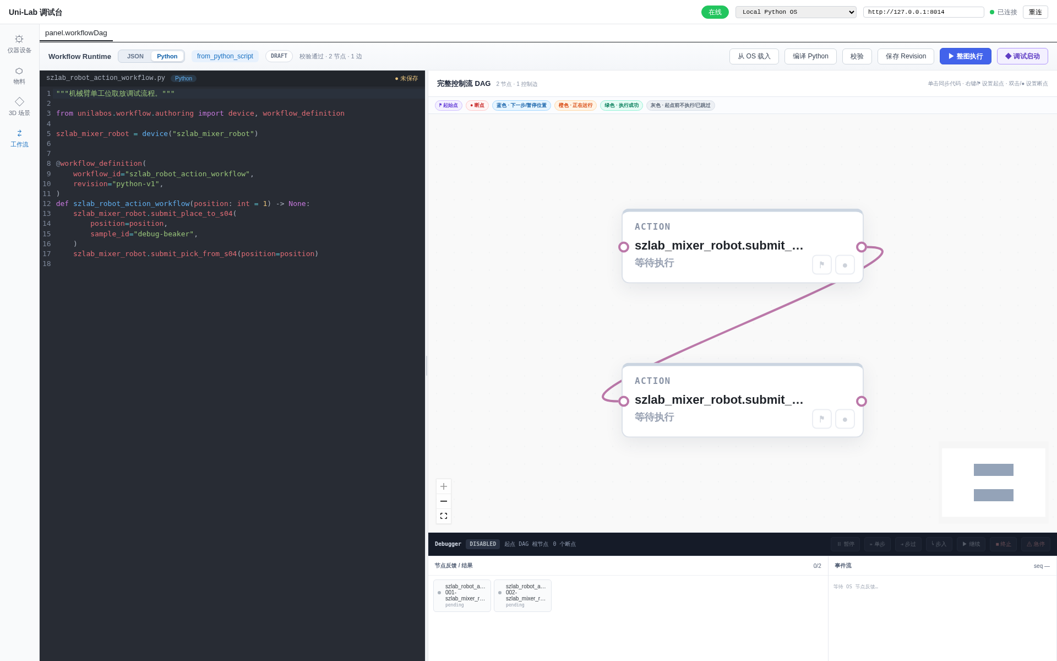
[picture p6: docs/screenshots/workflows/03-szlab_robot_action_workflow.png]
机械臂 S04 取放


### 4. S04 机械臂—磁搅

`s04_robot_stirring_workflow`：3 节点、2 边。

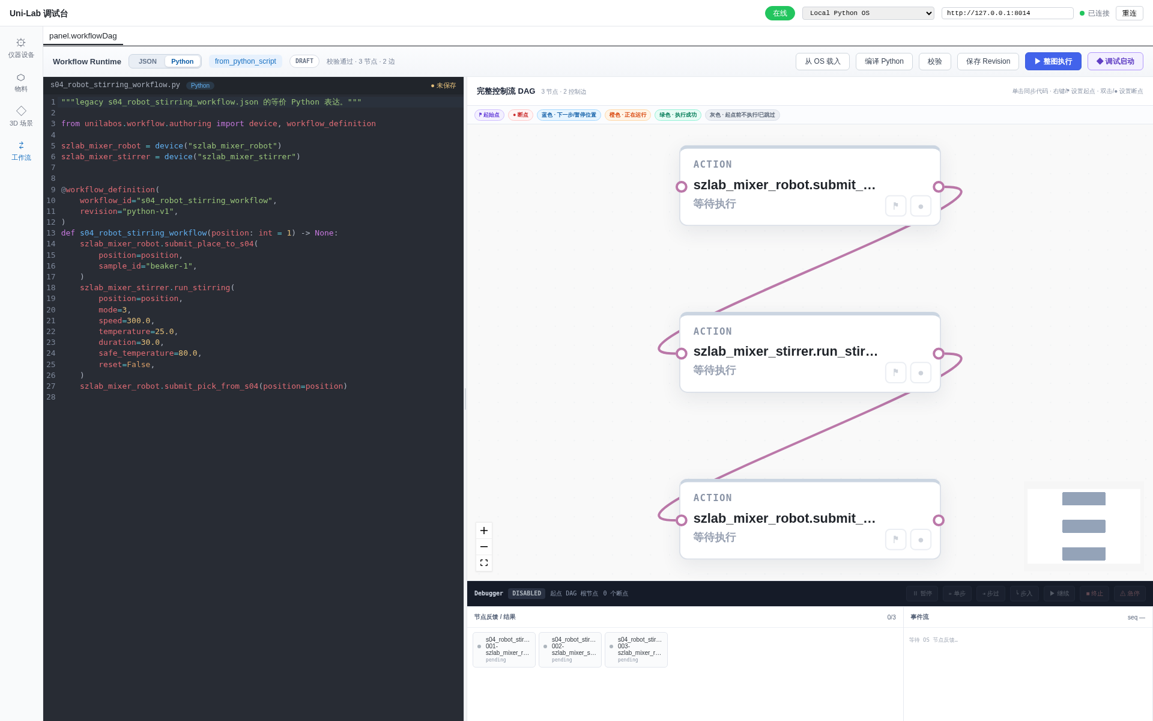
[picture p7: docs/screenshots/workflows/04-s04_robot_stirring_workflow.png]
S04 机械臂—磁搅


### 5. S06 机械臂—加液

`s06_robot_workflow`：3 节点、2 边。

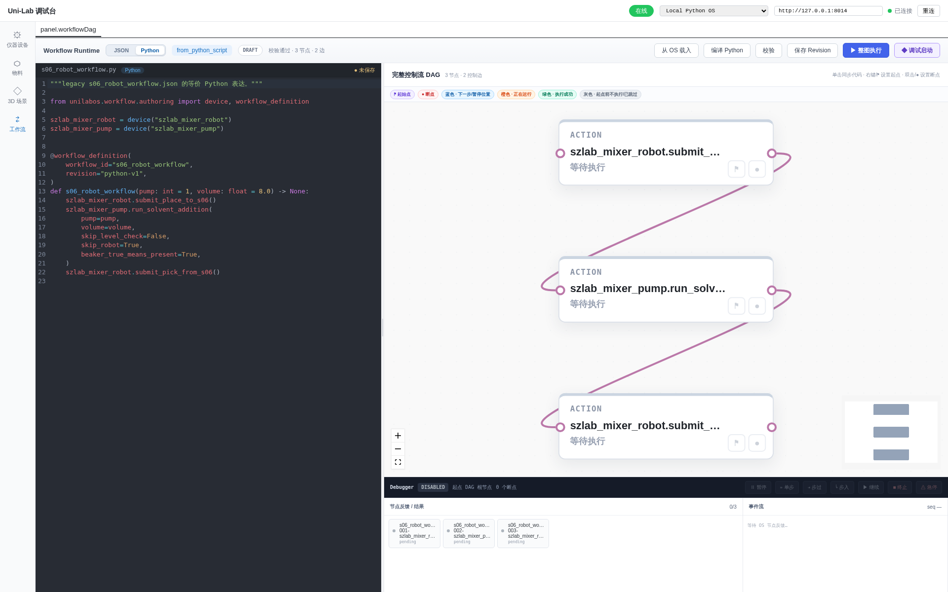
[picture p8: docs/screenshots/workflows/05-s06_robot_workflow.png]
S06 机械臂—加液


### 6. S07 机械臂搬运

`s07_robot_workflow`：3 节点、2 边。

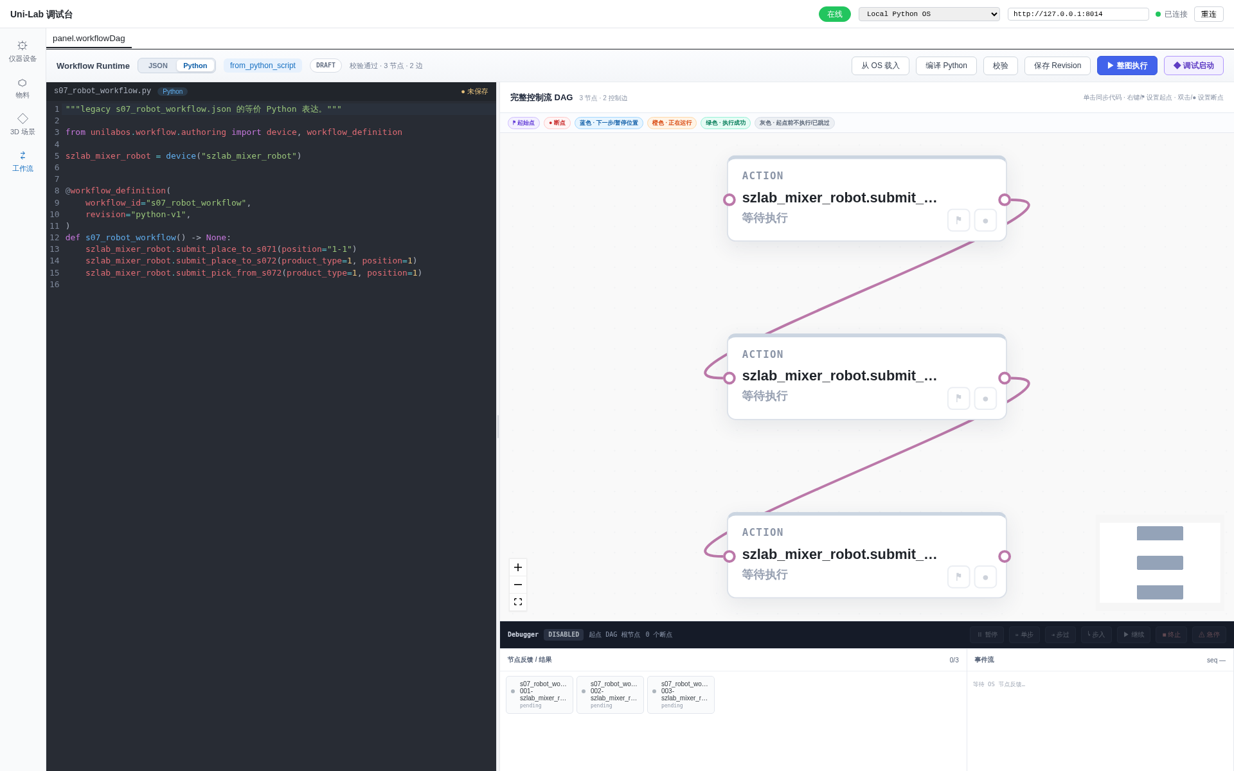
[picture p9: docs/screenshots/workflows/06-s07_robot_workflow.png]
S07 机械臂搬运


### 7. S07 固体投料

`szlab_s07_solid_addition_workflow`：3 节点、2 边。

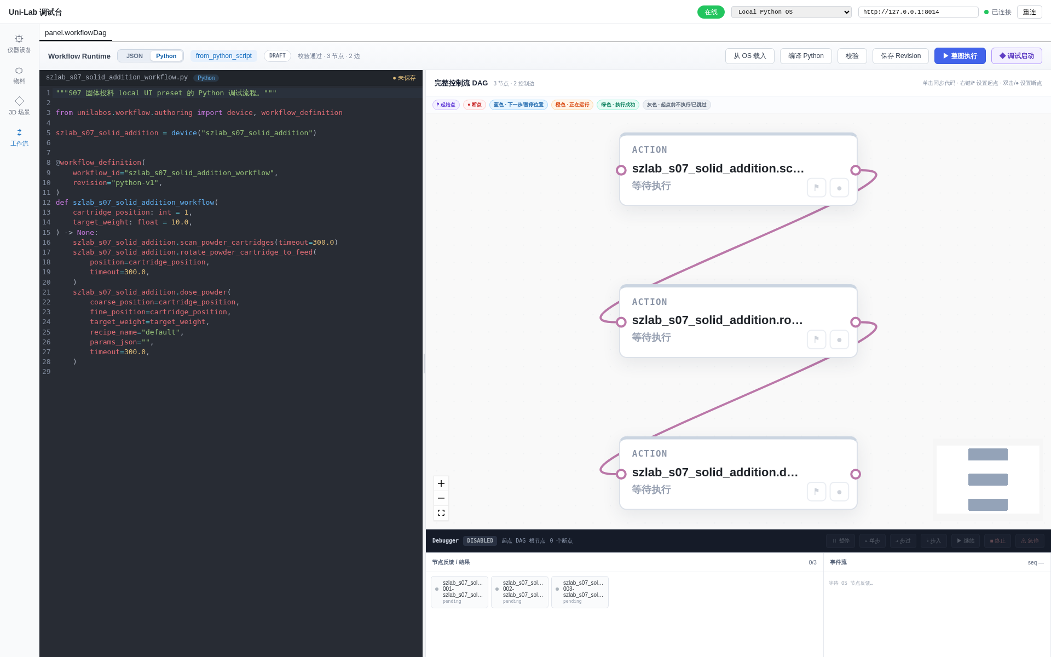
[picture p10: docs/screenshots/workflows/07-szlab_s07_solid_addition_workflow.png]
S07 固体投料


### 8. S08 开关盖

`s08_cap_workflow`：2 节点、1 边。

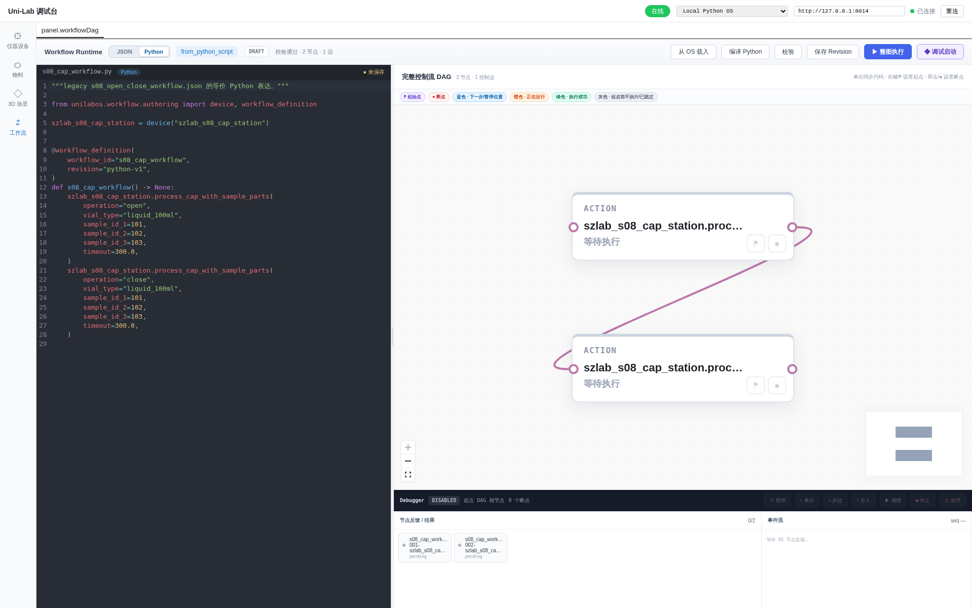
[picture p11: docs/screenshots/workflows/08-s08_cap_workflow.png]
S08 开关盖


### 9. S09 移液

`szlab_s09_pipetting_workflow`：4 节点、3 边。

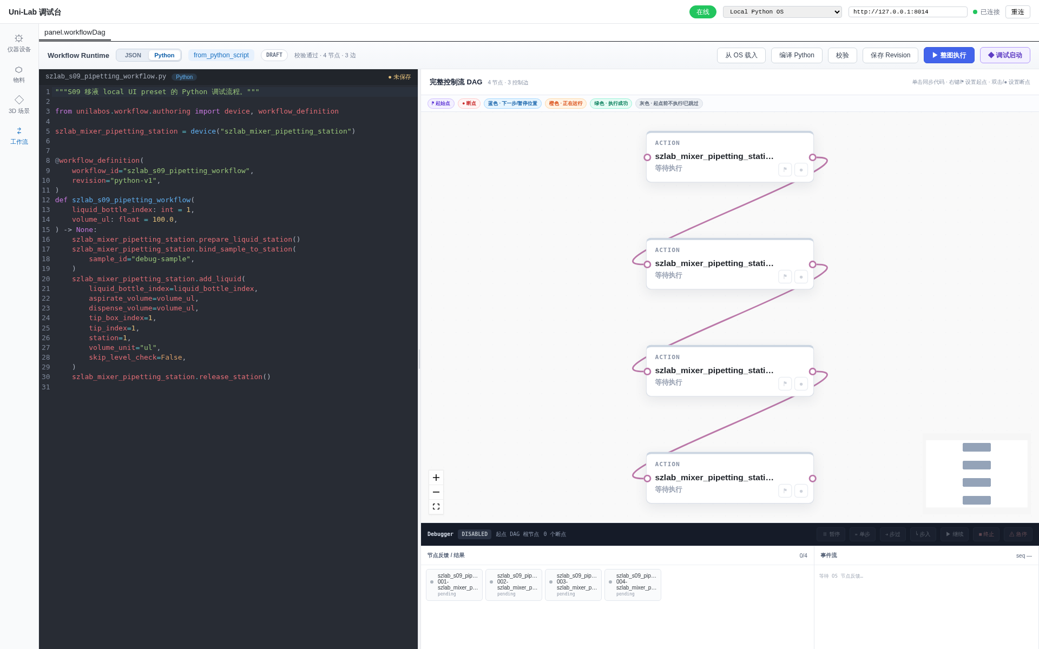
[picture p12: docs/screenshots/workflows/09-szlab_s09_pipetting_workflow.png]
S09 移液


### 10. 堆栈状态—S05—S06

`szlab_stack_s05_s06_workflow`：3 节点、2 边。

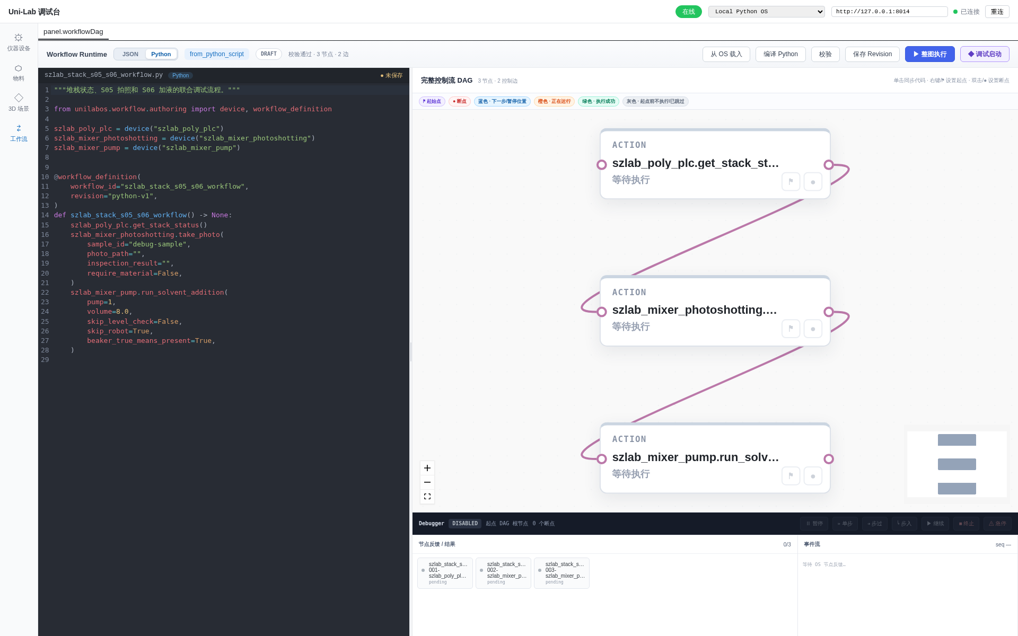
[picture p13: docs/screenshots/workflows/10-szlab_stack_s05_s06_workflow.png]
堆栈状态—S05—S06


### 11. Mixer 加液兼容流程

`szlab_mixer_workflow`：1 节点、0 边。

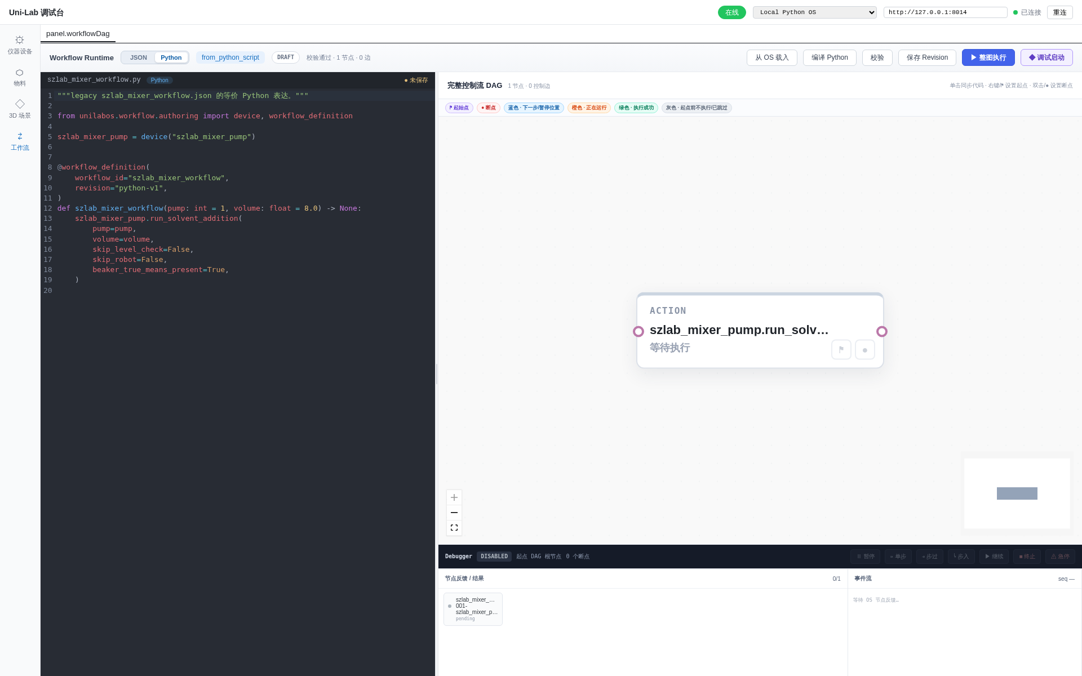
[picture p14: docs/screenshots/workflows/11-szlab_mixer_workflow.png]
Mixer 加液兼容流程


### 12. Mixer Pump 生产流程

`szlab_mixer_pump_production`：1 节点、0 边。

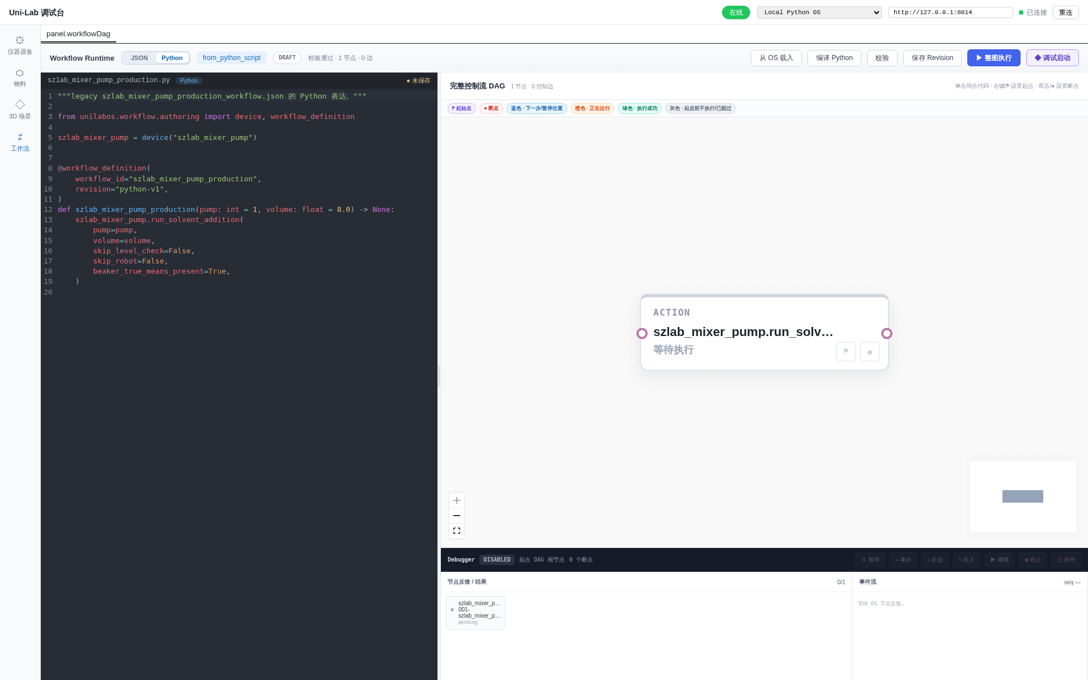
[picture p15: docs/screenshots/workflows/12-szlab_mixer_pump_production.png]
Mixer Pump 生产流程


## 复现

启动 SZLab 本地 bridge 与最新前端后运行：

```bash
./scripts/capture-all-workflows-e2e.sh
```

脚本自动发现 `szlab_poly_studio/workflows/` 下除 `__init__.py` 外的生产源码；数量不是 12、任一编译或
校验失败、节点数不一致、出现未预期的 HTTP/浏览器错误时都会失败。

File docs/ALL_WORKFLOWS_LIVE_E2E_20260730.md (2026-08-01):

# SZLab 全工作流远端 OPC UA 联调结果（2026-07-30）

## 结论

新版前端、Local Bridge、Edge、统一 PLC 通信模块和独立握手器已连接
`opc.tcp://opcua.ideawit.com:4855/xuse_sim` 完成 12 个 SZLab Python 工作流的逐一联调。

- 结果：`12/12 passed`
- 节点结果：全部 `success`
- 截图：每个工作流 3 张，共 36 张，分为运行中、完成态和事件流
- OPC UA NodeId 前缀：`ns=4;s=上位机通讯|`
- 前端：`http://127.0.0.1:5173`
- Bridge：`http://127.0.0.1:8015`
- Edge：`http://127.0.0.1:18003`
- Schedule：`ws://127.0.0.1:8892/api/v1/ws/schedule`

机器可读总结果见
[`result-summary.json`](screenshots/all-workflows-live-e2e-20260730/result-summary.json)。

## 工作流结果

| # | 工作流源码 | Run ID | 节点结果 | 截图 |
| --- | --- | --- | --- | --- |
| 1 | `magnetic_stirring.py` | `572f7d649302435990842cf955c838cc` | 1/1 success | [目录](screenshots/all-workflows-live-e2e-20260730/01-szlab_magnetic_stirring_workflow/) |
| 2 | `photoshotting.py` | `c346d965854643d8be37a9816e71d3ec` | 1/1 success | [目录](screenshots/all-workflows-live-e2e-20260730/02-szlab_photoshotting_workflow/) |
| 3 | `robot_action.py` | `291dfadd521c4c62aaa2ddcfc0b820ec` | 2/2 success | [目录](screenshots/all-workflows-live-e2e-20260730/03-szlab_robot_action_workflow/) |
| 4 | `s04_robot_stirring.py` | `6bf8156a03c54c589124c2f47b254dd2` | 3/3 success | [目录](screenshots/all-workflows-live-e2e-20260730/04-s04_robot_stirring_workflow/) |
| 5 | `s06_robot.py` | `908ef5f67baf481abae1fc0d0478e8b4` | 3/3 success | [目录](screenshots/all-workflows-live-e2e-20260730/05-s06_robot_workflow/) |
| 6 | `s07_robot.py` | `d519c5597a59486d838a28dab41e554e` | 3/3 success | [目录](screenshots/all-workflows-live-e2e-20260730/06-s07_robot_workflow/) |
| 7 | `s07_solid_addition.py` | `3543dd3cee0747ada4e76e99c4e52297` | 3/3 success | [目录](screenshots/all-workflows-live-e2e-20260730/07-szlab_s07_solid_addition_workflow/) |
| 8 | `s08_cap.py` | `bdf91a4752734197a144ca8fd5cb6853` | 2/2 success | [目录](screenshots/all-workflows-live-e2e-20260730/08-s08_cap_workflow/) |
| 9 | `s09_pipetting.py` | `70b0f5ef4a2f4df6babbb1722cfc8c2b` | 4/4 success | [目录](screenshots/all-workflows-live-e2e-20260730/09-szlab_s09_pipetting_workflow/) |
| 10 | `stack_s05_s06.py` | `a4135ccdad5b42e5a935aeff0aac6b1b` | 3/3 success | [目录](screenshots/all-workflows-live-e2e-20260730/10-szlab_stack_s05_s06_workflow/) |
| 11 | `szlab_mixer.py` | `215272bc84b04633a04585621fa112a9` | 1/1 success | [目录](screenshots/all-workflows-live-e2e-20260730/11-szlab_mixer_workflow/) |
| 12 | `szlab_mixer_pump_production.py` | `9d279a874e0e4c9581c37fca9fcf587a` | 1/1 success | [目录](screenshots/all-workflows-live-e2e-20260730/12-szlab_mixer_pump_production/) |

每个目录包含：

- `01-running.png`：工作流正在运行；
- `02-completed.png`：全部节点执行成功；
- `03-events.png`：运行事件流；
- `compiled-workflow.json`：前端编译后的工作流；
- `run-created.json`、`run-progress.json`、`run-final.json`、`run-timeline.json`；
- `handshake.log`：握手器对仿真服务器的变量交互；
- `result.json`：该工作流的机器可读结论。

汇总日志位于
[`logs/`](screenshots/all-workflows-live-e2e-20260730/logs/)。

## 联调中确认并修正的问题

1. Edge 必须使用独立、干净的运行 journal。旧的
   `~/.unilabos/runtime.sqlite` 中残留的动作锁会让新任务停在等待状态。本次通过
   `UNILABOS_RUNTIME_DB` 指向本次联调专用 SQLite 文件。
2. 远端 OPC UA 偶发超时或 `BadNodeIdUnknown` 时，统一 PLC 客户端会重连并有限重试；
   所有设备仍经同一个 PLC 通信模块读写，没有新增每设备 OPC UA 连接。
3. 完成信号不能在 Edge 读到新周期的 `False` 基线前立即变成 `True`。握手器默认
   `--process-delay` 已改为 5 秒。`stack_s05_s06.py` 随后以 5 秒延迟自动复跑成功，
   不需要人工修改变量。
4. S07 固体投料只复位该动作实际使用的既有变量，避免无关批量写入放大远端通信压力；
   没有在驱动、JSON 或仿真服务器中补充节点。
5. 纯泵工作流使用 `skip_robot=True`，符合工作流中不包含机器人动作节点的结构。

## 回归检查

- Python 测试：`48 passed`
- Ruff：通过
- SZLab 设备包注册表：`25/25` 通过，10 个设备类型解析成功
- Node E2E 脚本语法：通过
- Shell 启动脚本语法：通过
- 12 个工作流的 `result.json`：全部 `outcome=passed`

## 已知非阻断日志

Edge 在无云端登录信息的本地模式仍会记录云端启动配置/物料上传的 401；当前 Deck
资源转换还会记录 `Deck.__init__() got an unexpected keyword argument 'setup'`。这两类日志
没有阻止本地设备注册、动作调度或本次 12 个工作流完成。Edge 退出时后台属性发布线程还可能
记录一次 ROS publisher context 已关闭；该日志发生在所有工作流进入终态并正常发送
`normal_exit` 之后。

## 复现命令

服务启动后执行：

```bash
cd /home/changjunhan/Uni-Lab-Core/Uni-Lab-SZLab

UNILAB_HANDSHAKE_PROCESS_DELAY=5.0 \
  ./scripts/capture-all-workflows-live-e2e.sh
```

脚本会逐个导入 Python 工作流，通过前端启动运行，为每个工作流独立启动对应握手场景，
等待终态并输出截图和 JSON 证据。

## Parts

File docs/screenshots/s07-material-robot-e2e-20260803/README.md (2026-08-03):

# S07 双物料流 / ROS E2E 证据（2026-08-03）

## 最终结果

- 工作流：`S07 粉桶与烧杯搬运后固体称量`
- Workflow UUID：`5e7ce142-bf5a-5d30-8666-fdf5374941f1`
- Applied revision：`2`
- Applied Graph：`12` 节点、`9` 条边
- Task UUID：`6d63e2ae-ea19-4279-8b8e-92a504f6b447`
- Task 状态：`succeeded`
- Job：`10/10` succeeded，全部 `error_info=[]`
- 运行时间：`2026-08-03T06:35:43.642965Z` 至 `2026-08-03T06:36:13.666009Z`
- OS Task 日志窗口：`33739`–`43343` 行，`ERROR/Traceback/Exception/FAILED/failed` 为 `0`
- `添加物料失败` / `login verification`：整份本轮 OS 日志中均为 `0`
- 浏览器控制台 error：`[]`

最终截图：

- [完整画布、MaterialSource palette 与 Task 10/10](./material-flow-clean-task-10-of-10.png)
- [放大后的成功物料流](./material-flow-clean-readable-task-10-of-10.png)
- [折中缩放成功物料流](./material-flow-clean-balanced-task-10-of-10.png)

`workflow-task-ros-e2e-final.png` 是修复前失败记录，保留用于对比，不是最终结果。

## 分支与工作树

- Uni-Lab-OS：`/Users/dp/Design_projects/Uni-Lab-Core/.worktrees/os-material-integration`
  - 分支：`integration/workflow-task-runtime`
- SZLab package：`/Users/dp/Design_projects/Uni-Lab-Core/.worktrees/szlab-material-robot-e2e`
  - 分支：`codex/szlab-material-robot-e2e`
- 前端：`/Users/dp/Design_projects/Uni-Lab-Core/.worktrees/fe-os-migration-merge`
  - 分支：`integration/fe-os-migration`

## 确定性本地 E2E 边界

WorkflowTask 确实通过 ROS 后端执行；PLC/现场动作由本地确定性 OPC UA 服务器与
握手仿真器承接，没有连接真实设备。OS 未使用 `--test_mode`，并显式开启
`--enable_workflow_physical_execution`。这是完整 ROS/Action/调度/PLC 协议 E2E，
不是无硬件状态下对真实机械运动的声明。

完整启动 JSON：

- `runtime/material-robot-e2e-sim-full-v4/szlab-material-robot-e2e-full-v4.json`
- SHA-256：`e8fbb0a83172bca58030b79d755578208636cb6df4d36de280be9e9e3c9e4ee5`
- `129` nodes、`0` links
- PLC：`opc.tcp://127.0.0.1:50100/`、`auto_connect=true`、prefix `ns=4;s=上位机通讯|`
- 机械臂 standard actions、安全许可与远程自动许可均启用；journal 使用本轮独立路径

## 完整启动命令

本地 OPC UA：

```bash
PYTHONPATH=/Users/dp/Design_projects/Uni-Lab-Core/.worktrees/szlab-material-robot-e2e \
/Users/dp/miniforge3/envs/unilab/bin/python -u \
  scripts/szlab_local_opcua_server.py \
  --endpoint 'opc.tcp://127.0.0.1:50100/'
```

S07 协议握手：

```bash
PYTHONPATH=/Users/dp/Design_projects/Uni-Lab-Core/.worktrees/szlab-material-robot-e2e \
/Users/dp/miniforge3/envs/unilab/bin/python -u scripts/szlab_workflow_handshake.py serve \
  --workflow s07_material_dosing \
  --url 'opc.tcp://127.0.0.1:50100/' \
  --node-prefix 'ns=4;s=上位机通讯|' \
  --process-delay 0.5 \
  --poll-interval 0.1
```

从正确的 OS 分支使用 `unilab` CLI 启动 ROS OS：

```bash
PYTHONPATH=/Users/dp/Design_projects/Uni-Lab-Core/.worktrees/os-material-integration:/Users/dp/Design_projects/Uni-Lab-Core/.worktrees/szlab-material-robot-e2e \
/Users/dp/miniforge3/envs/unilab/bin/unilab \
  --workspace /Users/dp/Design_projects/Uni-Lab-Core/.worktrees/szlab-material-robot-e2e \
  --graph /Users/dp/Design_projects/Uni-Lab-Core/.worktrees/szlab-material-robot-e2e/runtime/material-robot-e2e-sim-full-v4/szlab-material-robot-e2e-full-v4.json \
  --config /Users/dp/Design_projects/Uni-Lab-Core/.worktrees/szlab-material-robot-e2e/deployment/local_config.py \
  --working_dir /Users/dp/Design_projects/Uni-Lab-Core/.worktrees/szlab-material-robot-e2e/runtime/material-robot-e2e-sim-full-v4 \
  --backend ros \
  --app_bridges websocket fastapi \
  --edge_scheduler \
  --ros_domain_id 91 \
  --port 18003 \
  --disable_browser \
  --skip_env_check \
  --enable_workflow_physical_execution
```

前端：

```bash
pnpm --filter @unilab/kernel-web dev --host 127.0.0.1 --port 5173
```

浏览器：

```text
http://localhost:5173/?section=workflow&localOsUrl=http%3A%2F%2F127.0.0.1%3A18003&disable=postFx
```

OS 启动确认：

```text
14:33:24.201 edge scheduler ready (ordering=local-stable)
14:33:24.258 Backend ros started.
14:33:24.482 启动FastAPI服务器: 0.0.0.0:18003
```

## 双 MaterialSource 与 `resource_ref`

普通 Action 参数现在可把 `resource_ref('id')` 当作与 `device('id')` 相同风格的声明式
引用：编译后由 Inventory 解析为 `ResourceSlot`，不再要求作者手写 UUID。MaterialSource
的 `mount=resource_ref(...)` 继续保留；前端恢复原生特殊节点渲染，而不是普通 Action 节点。

| 节点 | 解析后的 mount UUID | 分配的 material UUID | 状态 |
|---|---|---|---|
| `source_beaker` | `29f43434-ff8b-5246-b924-a20cddd452fc` | `c6ab5682-b465-49fd-85cb-b20f360b71f4` | succeeded |
| `source_powder` | `fa7b0692-2e78-5d5e-b789-9b0dfffb5dc7` | `c1b69585-e278-479c-99b3-2e36e66d8a50` | succeeded |

两个 MaterialSource 在 `06:35:43.442056Z` 同时完成，两个并行分支均立即 ready。
前端分别显示 `物料来源 / 主样品 · 已有物料 / Material 输出端口` 和
`物料来源 / 试剂 · 已有物料 / Material 输出端口`；Action 节点显示对应 Material 轨道。

## 调度、机器人独占与最终汇合

| Action | started_at | finished_at |
|---|---|---|
| `picked_beaker` / robot | `06:35:43.653751Z` | `06:35:47.970936Z` |
| `placed_beaker` / robot | `06:35:48.023888Z` | `06:35:51.452185Z` |
| `committed_beaker` / Host | `06:35:51.547615Z` | `06:35:51.631148Z` |
| `picked_powder` / robot | `06:35:51.822685Z` | `06:35:55.057160Z` |
| `prepared_powder` / S07 | `06:35:55.186785Z` | `06:35:57.420491Z` |
| `placed_powder` / robot | `06:35:57.534071Z` | `06:36:01.241615Z` |
| `committed_powder` / Host | `06:36:01.495242Z` | `06:36:01.790053Z` |
| `dosed` / S07 | `06:36:01.861894Z` | `06:36:13.600401Z` |

四个 `szlab_mixer_robot` Action 没有重叠。两个分支并行 ready，但由同一设备资源锁
串行执行；最终 `dosed` 同时接收 `beaker` 和 `powder_cartridge`：

```json
{
  "success": true,
  "beaker_uuid": "c6ab5682-b465-49fd-85cb-b20f360b71f4",
  "powder_cartridge_uuid": "c1b69585-e278-479c-99b3-2e36e66d8a50",
  "commanded_mass_g": 1.0,
  "message": "S07 固体称量流程完成；PLC 未提供实测质量"
}
```

OPC 握手记录覆盖机器人 pick/place、S07 粉桶位准备和最终投粉，全部出现
`accepted -> completed -> reset`。

## 日志、浏览器和回归

本轮 OS 日志：

- `runtime/material-robot-e2e-sim-full-v4/logs/2026-08-03 14-33-22.log`
- `14:35:43.445 POST /api/v1/workflow-tasks 201`（由前端创建）
- `14:35:43.650 Workflow Task running`
- `14:36:13.601 最终 dose Job succeeded`
- `14:36:13.672 Workflow Task succeeded`
- Task 行窗口 `33739`–`43343` 的错误扫描为空

节点 palette 的一次启动期 `Failed to fetch` 在点击“重新读取”后恢复，MaterialSource
palette 与特殊节点均出现；最终浏览器 console 的 error 级日志为空。

回归结果：

```text
Uni-Lab-OS 定向回归：145 passed
SZLab package 定向回归：61 passed
workflow-editor：27 files / 159 tests passed
services：11 files / 105 tests passed
workflow-editor typecheck：passed
services typecheck：passed
local OPC UA server py_compile：passed
local OPC UA server Ruff：passed
```

OS 回归覆盖普通 Action `resource_ref(...)` 编译/Inventory 解析、ResourceSlot 同步/异步
ROS JSON 输入、单棵嵌套 ResourceTreeSet dump、Host 本地资源同步不隐式调用云客户端，
以及显式 material bridge 仍被保留。

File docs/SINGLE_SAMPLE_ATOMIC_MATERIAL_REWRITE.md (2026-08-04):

# 单样品 38 动作 JSON 的物料感知改写

状态：2026-08-04 已进入 PackageCatalog 的生产源码。本文对应附件
`ozr3xzczpml1e5chr8ik43mc0-szlab_single_sample_atomic_workflow.json`，目标 Python 源码见
[`single_sample_atomic_material.py`](../szlab_poly_studio/workflows/single_sample_atomic_material.py)；
未规范化前的说明性版本保留在
[`single_sample_atomic_material_target.py`](examples/workflow_authoring/single_sample_atomic_material_target.py)。

这不是把 38 个旧方法逐行换名，而是把“位置型控制序列”重建为有物料身份、有转运提交、有
多物料汇合和命名输出的 Workflow。生产源码和一个通用标准转运子工作流已经登记
`package.yaml`，并通过“先发布子工作流、再发布主工作流”的真实 Authoring 生命周期。
第 6 节仍列出现场机械臂部署必须 fail-closed 验收的 Site/见证项；软件进入生产目录不等于绕过
点位、负载或传感器验收。

## 1. 原文件的输入事实

原文件顶层只有 `name` 和一个 rule：`S10 取试剂瓶 == true` 的 rising edge 触发，随后按
`index=1..38` 执行 action。它记录了工艺顺序，但没有材料节点、材料边、Host 物料归属提交或
真正的条件表达式。

原附件还有两个格式缺陷，重写时按可恢复的业务意图处理：

- 第 10 个 action 重复声明 `node` key；两个值相同，不影响语义恢复。
- 第 24 个 action 后多一个 `}`，所以附件不是严格可解析的 JSON。

另外，第 7-8、11-12 步的注释声称“根据扫码结果决定是否执行”，但 action 数组本身没有条件边；
旧执行器仍会顺序执行它们。新主流程不会继续这种“注释条件”。

## 2. 改写后的材料合同

| 材料 | 新入口 | 主线 | 最终位置/输出 |
|---|---|---|---|
| 500 mL 烧杯 | `MaterialSource(beaker_500ml)` | S03 → S07 → S06 → S09 → S04 → S05 → 倒料 → S11 | `used_beaker` |
| 250 mL 样品瓶 | `MaterialSource(sample_vial_250ml)` | S03 → S08 开盖 → 接收样品 → 关盖 → S11 | `product_vial` |
| 100 mL 液体试剂瓶 | Workflow `ResourceSlot` input | S10 → S08 开盖 → S09 移液 | `reagent_bottle` |
| 粗注粉瓶 | `MaterialSource(powder_container)` | 粉桶仓 → S07 P01 → 投粉 | `coarse_powder_cartridge` |
| 精注粉瓶 | `MaterialSource(powder_container)` | 粉桶仓 → S07 P02 → 投粉 | `fine_powder_cartridge` |
| S09 TIP | Workflow `ResourceSlot` input | S09 取 TIP → 移液 → 放 TIP/更新 disposition | `tip` |
| S06 泵 1 溶剂 | Workflow `ResourceSlot` input | S06 储液位 → 烧杯内容物 | 同名 Action output |
| S06 泵 2 溶剂 | Workflow `ResourceSlot` input | S06 储液位 → 烧杯内容物 | 同名 Action output |

试剂瓶、TIP 和两路 S06 溶剂暂用 Workflow input，是因为当前部署图还没有为这些具体业务物料
发布可供 admission 选择的完整 MaterialSource 库存事实；这仍是完整 `ResourceSlot` 合同，不是
`sample_id` 替代物。它们所在的已知仓库不再重复作为 Workflow input：例如 S10 直接写为
`resource_ref("s10_liquid_reagent")`。

### 2.1 Warehouse 与 Site 的边界

主 Workflow 只暴露业务运行时必须选择的输入。启动图已经唯一确定的 Warehouse 全部在流程内部
用稳定资源 ID 绑定：

```python
source_warehouse = resource_ref("s3_unused_beaker")
powder_warehouse = resource_ref("powder_container_warehouse")
s04_warehouse = resource_ref("s04_process_warehouse")
```

所有 Site（如 `L1B1`、`S0721`、`S061`、`BEAKER1`、`S041`、`S051`、`S081`）都是当前工艺与
启动部署共同确定的内部常量，不作为顶层参数，也不再先定义一组“整体变量”再传递。这样调用者
不能把 S07 的烧杯误送到粉瓶位，也不会把部署配置伪装成每次 Task 的业务输入。

当前启动图尚未发布 S08/S09 的 typed process Warehouse 实例，因此主流程暂时只保留
`s08_warehouse`、`s09_warehouse` 两个 `ResourceSlot` 输入，并继续受第 6 节现场门禁约束。待启动图
补齐这两个稳定资源 ID 后，应按同一规则改成内部 `resource_ref(...)`，届时无需改变 Site 写法。

## 3. 新拓扑

```mermaid
flowchart TD
    start([WorkflowTask inputs + MaterialSource admission]) --> scan[S07 粉桶扫码/事实核验]

    scan --> p0
    subgraph p0[无条件并行准备；共享同一机械臂 Claim]
      direction LR
      reagent[试剂瓶：S10 → S08 开盖 → S09]
      coarse[粗注粉瓶：粉桶仓 → S07 P01]
      fine[精注粉瓶：粉桶仓 → S07 P02]
      beaker[烧杯：S03 → S07 S0721]
      vial[样品瓶：S03 → S08 开盖]
    end

    reagent --> dose
    coarse --> dose
    fine --> dose
    beaker --> dose[S07 投粉：粗粉瓶 + 精粉瓶 + 烧杯]
    vial --> pour

    dose --> s06move[烧杯转运至 S06]
    s06move --> s06[S06：烧杯 + 两路溶剂]
    s06 --> s09move[烧杯转运至 S09]
    reagent --> s09[S09：烧杯 + 试剂瓶 + TIP]
    s09move --> s09
    s09 --> s04move[烧杯转运至 S04]
    s04move --> stir[S04 物料感知搅拌]
    stir --> s05move[烧杯转运至 S05]
    s05move --> inspect[S05 物料感知拍照检测]
    inspect --> pour[机械臂持杯倒入已开盖样品瓶]

    pour --> final_parallel
    subgraph final_parallel[倒料后的无条件并行]
      direction LR
      beaker_home[烧杯 place → Host commit → S11]
      close_vial[S08 关闭样品瓶]
    end
    close_vial --> vial_home[样品瓶 transfer → S11]
    beaker_home --> output([命名 Workflow output])
    vial_home --> output
```

`parallel()` 只去掉源码顺序依赖，不承诺两次机器人运动物理同时发生。所有
`material_transfer` 子流程内部都绑定 `device("szlab_mixer_robot")`，所以多个 ready Job 竞争同一
机械臂实例，由 Scheduler/Execution Claim 串行取得运动权；S07、S08 等其他设备在没有 Claim
冲突时可以重叠工作。

## 4. 统一的转运表达

旧 JSON 的普通机械臂取放成对折叠为同一个复合 Workflow：

```python
transferred = material_transfer(
    resource=upstream.resource,
    source_warehouse=resource_ref("s04_process_warehouse"),
    target_device="target-device-id",
    target_warehouse=resource_ref("s05_process_warehouse"),
    source_site="S041",
    target_site="S051",
)
```

其内部固定为：

```text
robot.pick(resource, source Warehouse, source Site)
  → robot.place(resource, target Warehouse, target Site)
  → host.transfer_resource(resource, target device, target Warehouse, target Site)
```

`pick/place` 只执行物理动作并透传同一个 Material UUID；只有最后一步修改 OS 物料树。任何
`FAILED/UNKNOWN` 都不得进入 Host commit。业务签名不包含 `transfer_id` 或 `command_id`；驱动从
OS 注入的 `WorkflowNodeJob.uuid` 取得唯一 command identity。同一个 Job 重试会命中原 journal
记录，新 Task 的新 Job 自动得到新 identity。

不再为烧杯、粉瓶、样品瓶和液体试剂瓶各复制一份相同转运 Workflow。唯一的通用
`material_transfer` 接受 `ResourceSlot`；它不在显式结果记录里声明一个无约束 `resource`，而由
同名输入合成隐式透传 output。因此父图可继续从实际上游证明具体物料模板，下游
`AllowedResourceTemplates(...)` 约束不会因复用通用转运而丢失。

第 33-35 步是例外：烧杯从 S05 取出后保持在夹爪中完成倒料，最后直接放到 S11。因此它被表达为
`robot.pick → robot.pour_beaker_into_vial → robot.place → host.transfer_resource`，不能伪装成
普通点到点转运，也不能在倒料前提前提交一个不存在的 S08 烧杯落座事实。

## 5. 38 步改写前后对应关系

| 旧序号 | 旧节点 / method | 新表达 | 物料与语义变化 |
|---:|---|---|---|
| 1 | S10 取试剂瓶 / `submit_pick_from_s10(position=1)` | `reagent_at_s08 = material_transfer(...)` 内部 `robot.pick` | 输入改为具体试剂瓶 `ResourceSlot` 与 S10 Warehouse/Site；幂等身份由 Node Job 注入。 |
| 2 | S08 放瓶 / `submit_place_to_s08(product_type=3, position=2)` | 同一 `material_transfer` 内部 `robot.place` + Host commit | `product_type/position` 降为 Site binding；成功后才把同一试剂瓶记到 S08。 |
| 3 | S08 开盖 / `process_cap(工艺选择=5, 样品ID=[101], 瓶盖暂存位=1)` | `process_cap_with_material(container=reagent_at_s08.resource, operation="open", vial_type="liquid_100ml")` | 试剂瓶成为显式 input/output；`sample_id` 仅为业务追踪，不再代表材料身份。 |
| 4 | S08 取瓶 / `submit_pick_from_s08(...)` | `reagent_at_s09 = material_transfer(...)` 内部 `robot.pick` | 消费第 3 步输出的同一个试剂瓶。 |
| 5 | S09 放料 / `submit_place_to_s09(product_type=2, position=1)` | 同一 `material_transfer` 内部 `robot.place` + Host commit | 目标变成 S09 试剂瓶 Site；需补 S09 试剂瓶在位见证。 |
| 6 | S07 粉罐扫码盘点 / `scan_powder_cartridges()` | 保留 `scan_powder_cartridges()`，位于并行准备前 | 只核验/更新 S07 事实，不再靠注释控制后续节点。 |
| 7 | S072 位置 1 取旧粉罐 / `submit_pick_from_s072(...)` | 从主流程删除；目标 Site 非空时 admission fail-closed | “有旧罐才执行”改由独立清场/对账 Workflow 处理，不能无条件搬未知物料。 |
| 8 | 旧粉罐放回 S071 / `submit_place_to_s071(position="auto")` | 与第 7 步一起移入独立清场 Workflow | 清场也必须有旧粉罐 `ResourceSlot` 和一次完整 transfer/Host commit。 |
| 9 | S071 取粉罐并旋转到上料位 / `submit_pick_from_s071_and_rotate_to_feed(...)` | `prepare_powder_cartridge_site(...)` + 粗粉 `material_transfer` 的 `robot.pick` | 原本耦合的 S07 转位与机器人动作拆开；各自取得设备 Claim。 |
| 10 | 粗粉罐放到 S072 / `submit_place_to_s072(...)` | 粗粉 `material_transfer` 的 `robot.place` + Host commit 到 `P01` | 粗粉罐形成独立线性材料链。 |
| 11 | S072 位置 2 取旧粉罐 | 与第 7 步相同，从主流程删除 | 目标 P02 占用由 admission 检查。 |
| 12 | 第二只旧粉罐放回 S071 | 与第 8 步相同，移入清场 Workflow | 不使用 `position="auto"` 隐藏 Site 选择和记账。 |
| 13 | 第二只粉罐取料并转位 | `prepare_powder_cartridge_site(...)` + 精粉 `material_transfer` 的 `robot.pick` | 与粗粉链分离，可与其拓扑并行，仍竞争同一机械臂。 |
| 14 | 精粉罐放到 S072 | 精粉 `material_transfer` 的 `robot.place` + Host commit 到 `P02` | 精粉罐有自己的 Material UUID 和 edge。 |
| 15 | S03 取 500 mL 烧杯 / `submit_pick_from_s03(...)` | `beaker_at_s07 = material_transfer(...)` 内部 `robot.pick` | 烧杯来自 `MaterialSource(beaker_500ml)`。 |
| 16 | 烧杯放到 S072 位置 1 | 同一 transfer 的 `robot.place` + Host commit 到 `S0721` | 下游 S07 Action 直接消费 `beaker_at_s07.resource`。 |
| 17 | S07 注粉 / `dose_powder(coarse_position=1, fine_position=1, ...)` | `dose_powder_with_two_materials(coarse_powder_cartridge, fine_powder_cartridge, beaker, ...)` | 三个 required material input 形成 AND 汇合；修正旧参数把粗/精位置都写 1 的歧义。 |
| 18 | 从 S072 取烧杯 | `beaker_at_s06 = material_transfer(...)` 内部 `robot.pick` | 消费投粉后的烧杯 output。 |
| 19 | 烧杯放到 S06 | 同一 transfer 的 `robot.place` + Host commit | OS 归属成功后 S06 才能加工。 |
| 20 | S06 双泵各加 10 / `run_solvent_addition(...)` | `add_solvent_with_materials(beaker, solvent_pump_1, solvent_pump_2, ...)` | 补出旧 JSON 缺失的两路溶剂 ResourceSlot；Action 提交数量/内容物变化。 |
| 21 | 从 S06 取烧杯 | `beaker_at_s09 = material_transfer(...)` 内部 `robot.pick` | 消费 S06 的 `beaker` output。 |
| 22 | 烧杯放到 S09 | 同一 transfer 的 `robot.place` + Host commit | 目标为 S09 烧杯 Site。 |
| 23 | S09 取 TIP、取液、放液、放 TIP / `add_liquid_to_beaker(...)` | `add_liquid_with_materials(beaker, reagent_bottle, tip, ...)` | 烧杯、试剂瓶、TIP 三条 edge 汇合；更新试剂量、烧杯内容物和 TIP disposition。 |
| 24 | 从 S09 取烧杯 | `beaker_at_s04 = material_transfer(...)` 内部 `robot.pick` | 消费移液后的烧杯。 |
| 25 | 烧杯放到 S04 | 同一 transfer 的 `robot.place` + Host commit 到 `S041` | `sample_id` 不再作为机器人材料参数。 |
| 26 | S04 磁搅 / `run_stirring(...)` | `stir_beaker(beaker=beaker_at_s04.resource, ...)` | 标量工艺参数保留，增加烧杯同名 input/output。 |
| 27 | S03 取样品瓶 | `sample_vial_at_s08 = material_transfer(...)` 内部 `robot.pick` | 样品瓶来自独立 MaterialSource；准备链前移到并行块。 |
| 28 | 样品瓶放到 S08 | 同一 transfer 的 `robot.place` + Host commit | 仍竞争同一机械臂，但不再强制等磁搅结束。 |
| 29 | S08 打开样品瓶盖 | `process_cap_with_material(container=sample_vial_at_s08.resource, operation="open", ...)` | 样品瓶同名透传；S08 与试剂瓶开盖通过设备 Claim 互斥。 |
| 30 | 从 S04 取烧杯 | `beaker_at_s05 = material_transfer(...)` 内部 `robot.pick` | 消费搅拌后的烧杯。 |
| 31 | 烧杯放到 S05 | 同一 transfer 的 `robot.place` + Host commit 到 `S051` | 下游检测由材料 edge 驱动。 |
| 32 | S05 拍照检测 / `take_photo(sample_id, ...)` | `inspect_beaker(beaker=beaker_at_s05.resource, ...)` | 烧杯显式透传；照片路径和算法结果成为 typed output。 |
| 33 | 从 S05 取烧杯 | `picked_for_pour = robot.pick(...)` | 进入“持杯倒料”复合段；此时不提交虚假的中间落座。 |
| 34 | S08 将烧杯倒入样品瓶 / `submit_pour_from_s08(...)` | `pour_beaker_into_vial(beaker, sample_vial, ...)` | 两个材料 input 汇合；Action 必须提交内容物从烧杯到样品瓶的事实。 |
| 35 | 烧杯放到 S11 | `robot.place(...)` + `host.transfer_resource(...)` | 只有最终 place 成功后，烧杯归属从 S05 原子变更到 S11。 |
| 36 | S08 关闭样品瓶盖 | `process_cap_with_material(container=poured.sample_vial, operation="close", ...)` | 与烧杯回 S11 放在 `parallel()`；二者无数据依赖且使用不同设备。 |
| 37 | 从 S08 取样品瓶 | `product_vial_at_s11 = material_transfer(...)` 内部 `robot.pick` | 消费关盖后的样品瓶 output。 |
| 38 | 样品瓶放到 S11 | 同一 transfer 的 `robot.place` + Host commit | 输出 `product_vial`；Workflow 成功条件同时等待使用后烧杯回库。 |

触发器不再是 Workflow 内部 action。`S10 取试剂瓶 rising edge` 应由唯一 Task Authority 转换为一次
幂等 `WorkflowTask` 创建请求；`log_nodes` 也不再是身份源，观测由稳定 node UUID、Job、Command
和 material progress 投影生成。

## 6. 生产部署门禁与已完成合同

| 缺口 | 要求 |
|---|---|
| S08/S09 typed Site owner | 为瓶位、烧杯位、试剂瓶位建立稳定 Warehouse/Site UUID、直接父子关系和部署图实例。 |
| S08 Site 见证 | 当前旧驱动的 place 1-5 与 pick 1-2 传感器集合不对称；现场确认前不能声称同一 Site 可闭环取放。 |
| S09 试剂瓶见证 | 当前代码明确写着 CSV 未提供试剂瓶传感器映射；标准 `pick/place` 必须 fail-closed。 |
| 250 mL 样品瓶负载 | 当前标准机械臂只接受 `sample_vial_500ml@v1`；要么补 250 mL payload/点位验收，要么由业务确认改用 500 mL，不能静默替换。 |
| S07 双粉瓶 Action（已完成） | `dose_powder_with_two_materials` 分别声明粗粉瓶、精粉瓶和烧杯 ResourceSlot。 |
| S06 多材料 Action（已完成） | `add_solvent_with_materials` 声明烧杯与两路实际储液 Material。 |
| S08/S09/S04/S05 Action（已完成） | 开关盖、移液、搅拌和检测均有 `ResourceSlot` input/output 与命名结果。 |
| 倒料 Action（软件合同已完成） | `pour_beaker_into_vial` 显式消费烧杯与 250 mL 样品瓶，并沿用旧 PLC 通信；现场仍须验收负载/点位/见证。 |
| C1 composite（已完成） | 唯一的通用 `material_transfer` 已通过 imported subworkflow、输入/输出 binding、非透明完成语义和 round-trip；材料模板约束由同名 `ResourceSlot` 隐式透传保持。 |
| Host Catalog（已完成） | `host.transfer_resource` 作为 typed authoring Action 唯一解析，并且只在 `place` 成功后执行。 |

生产化不得用以下方式绕过缺口：回退到 `submit_*`、继续用 `product_type/sample_id` 代替材料、
在 `place` 前调用 Host commit、伪造传感器、把 250 mL 当作 500 mL，或用 no-op Join 掩盖多材料
依赖。

## 7. 验收重点

- 源码中没有旧 `submit_*` 调用。
- 每个普通转运都收敛到 `material_transfer`；特殊倒料段显式解释为何不是普通转运。
- 四个 MaterialSource 使用 literal resource template、literal `resource_ref(稳定资源 ID)` 和明确 flow role。
- 启动图已确定的 Warehouse 不出现在 Workflow 参数中，全部由内部 `resource_ref(启动资源 ID)` 绑定。
- 所有 Site 都是调用点 literal，不出现在 Workflow 参数中，也不提升为 Workflow 级变量。
- 粗粉、精粉、烧杯在 S07 Action 形成三个独立 material input。
- 烧杯、试剂瓶、TIP 在 S09 Action 形成三个独立 material input。
- 同一个普通材料 output 不 fan-out 到两个物理分支。
- 两个 `parallel()` 都是无条件分支；共享机器人通过实例 Claim 互斥。
- `SingleSampleMaterialResult` 显式输出成品瓶、使用后烧杯、剩余试剂/粉瓶、TIP 和检测结果。
- Python→DAG→Python fixed-point 后没有 synthetic Fork/Join Node。
- 任一机器人 `UNKNOWN`、物料提交失败或 Site 见证不一致都会阻止后续加工和 Workflow 成功。

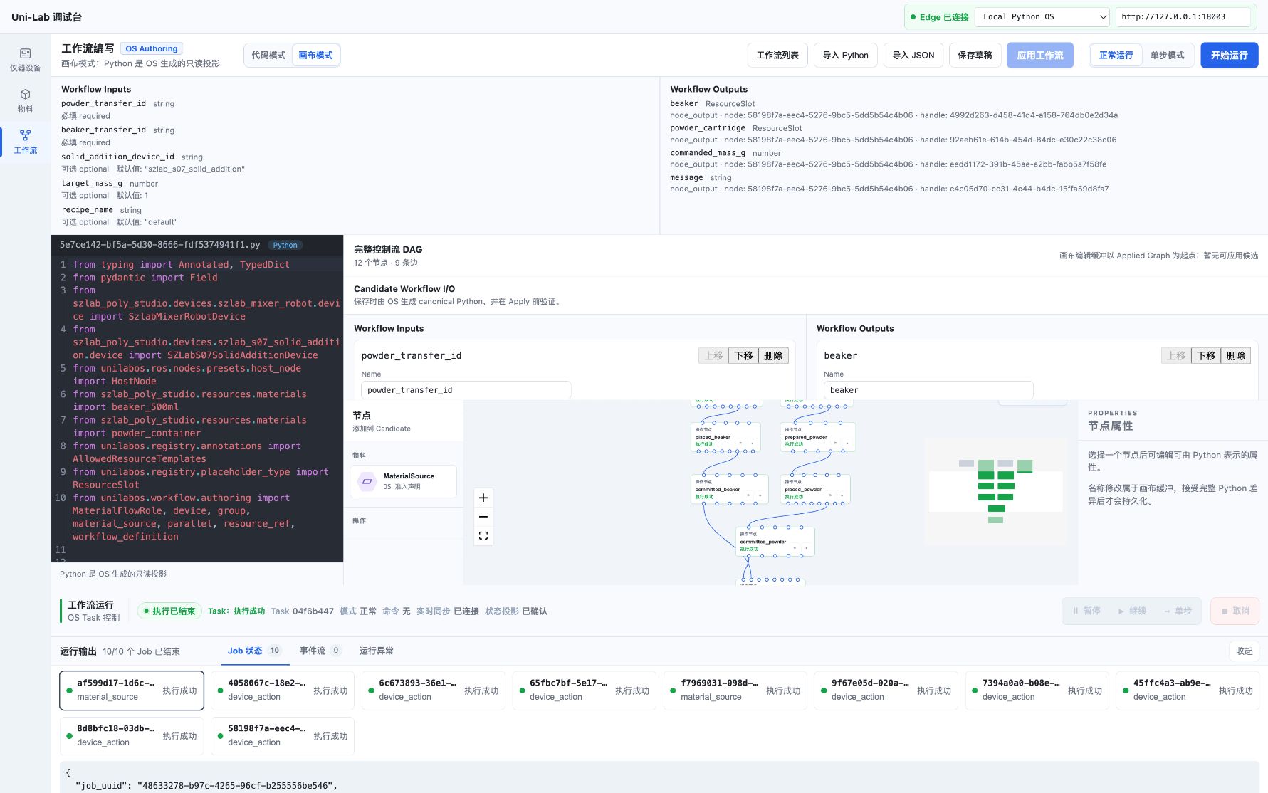
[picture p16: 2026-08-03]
docs/screenshots/s07-material-robot-e2e-20260803/material-flow-clean-readable-task-10-of-10.png

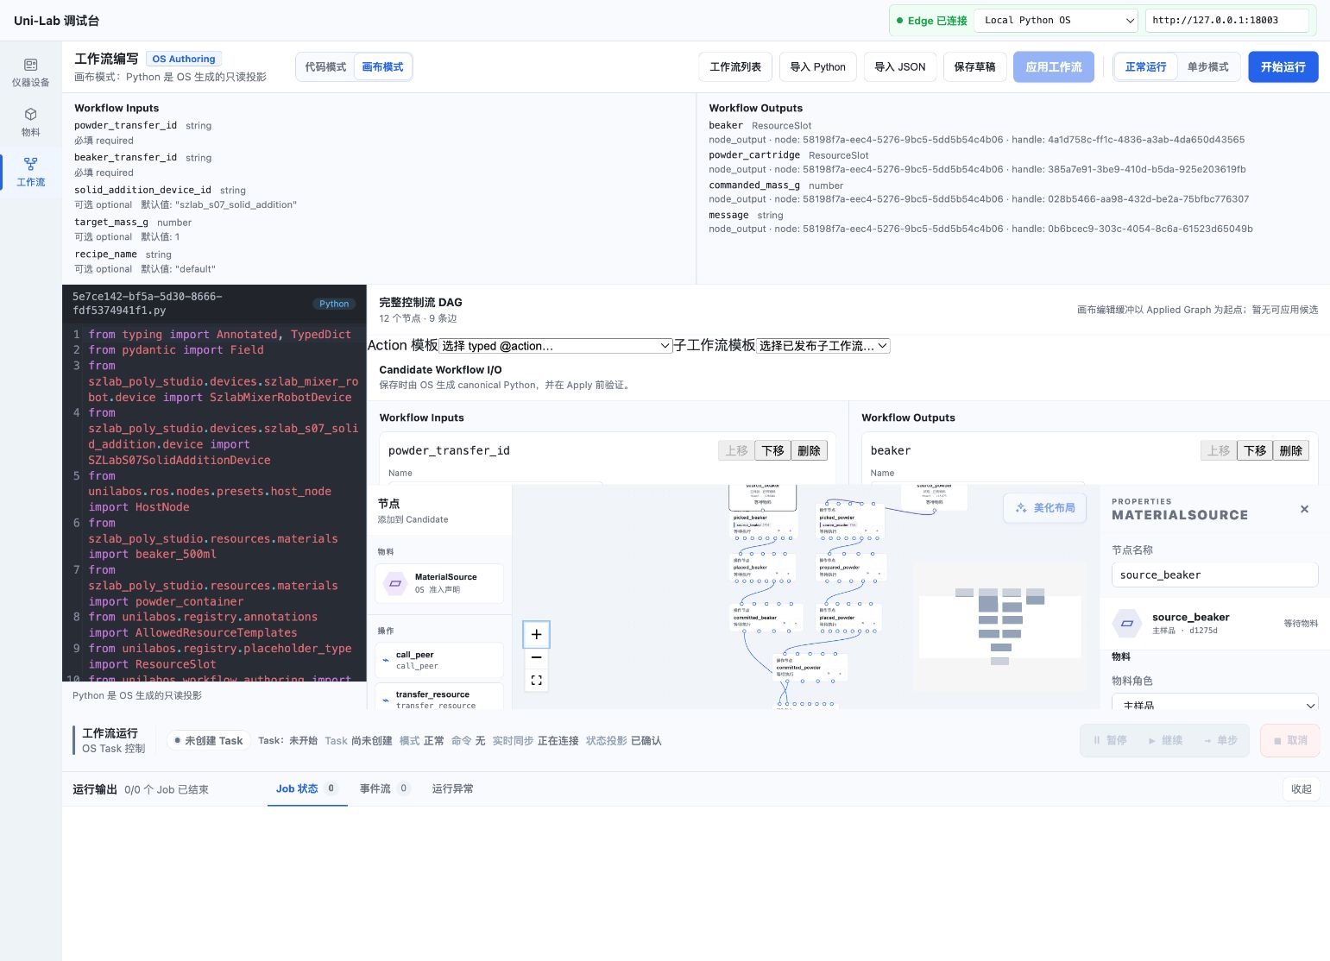
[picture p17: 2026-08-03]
docs/screenshots/s07-material-robot-e2e-20260803/material-source-integrated-fe-e2e.png

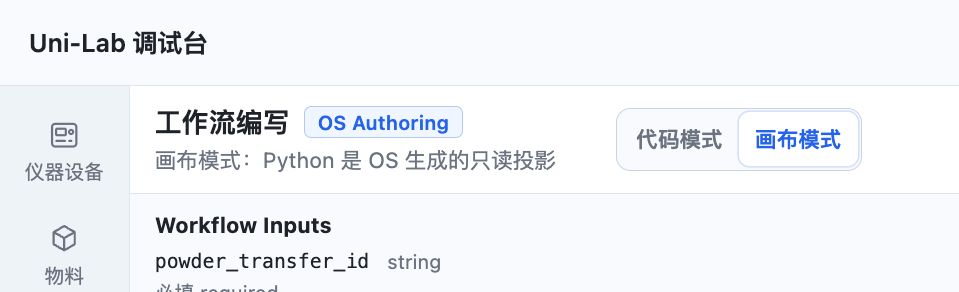
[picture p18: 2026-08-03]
docs/screenshots/s07-material-robot-e2e-20260803/material-flow-canvas-special-nodes-10-of-10.png

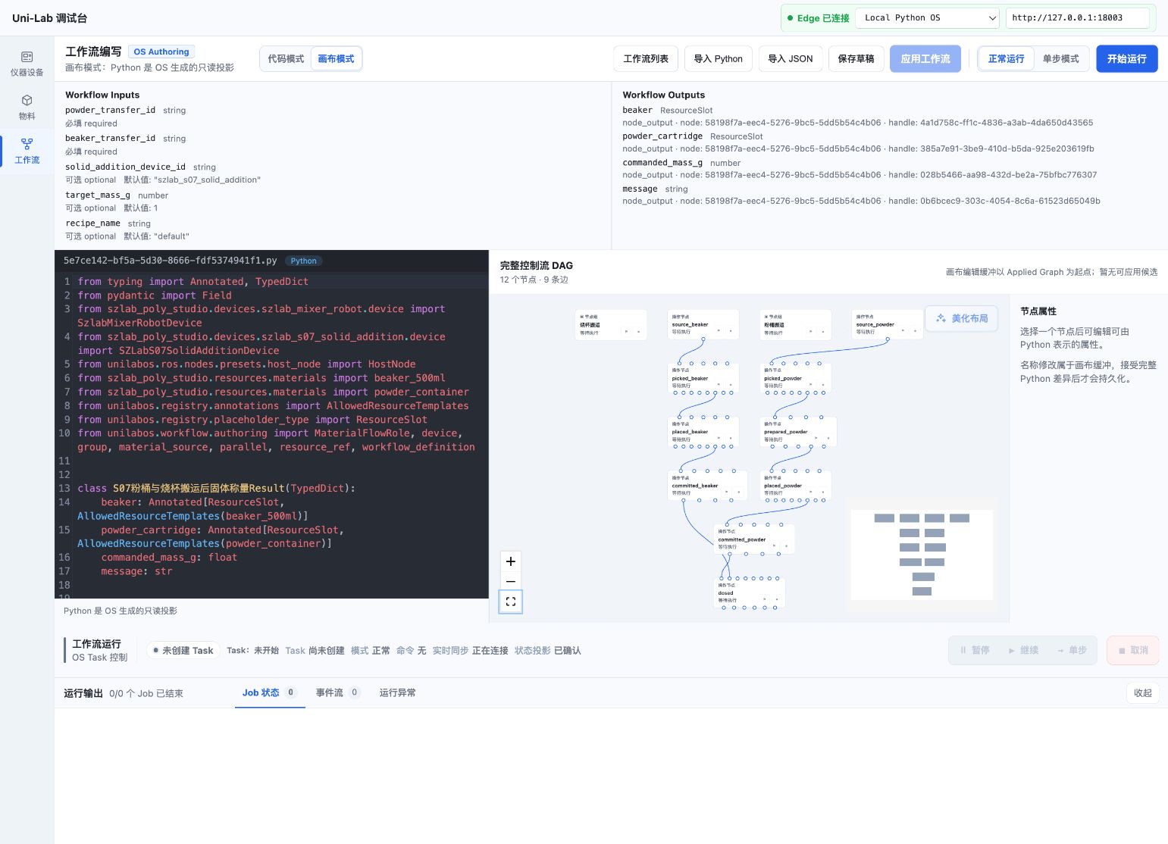
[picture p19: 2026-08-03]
docs/screenshots/s07-material-robot-e2e-20260803/applied-workflow-v2.png

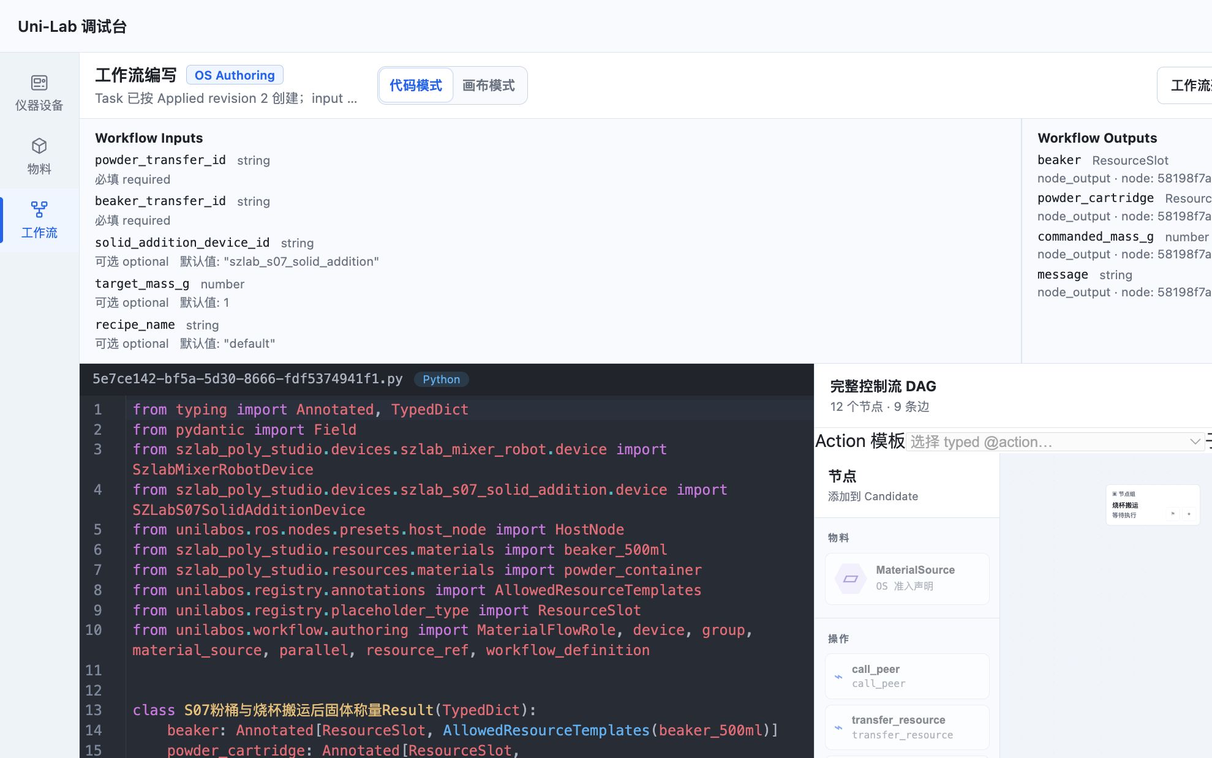
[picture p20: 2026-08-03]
docs/screenshots/s07-material-robot-e2e-20260803/workflow-task-ros-local-e2e-10-of-10.png

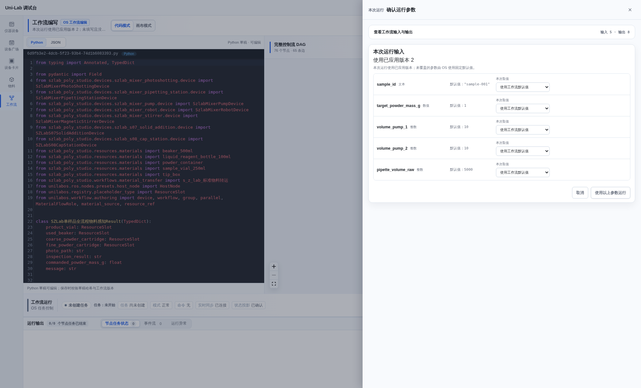
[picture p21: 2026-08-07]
docs/screenshots/LOCAL-195-plc-sim-material-source-run-input.png

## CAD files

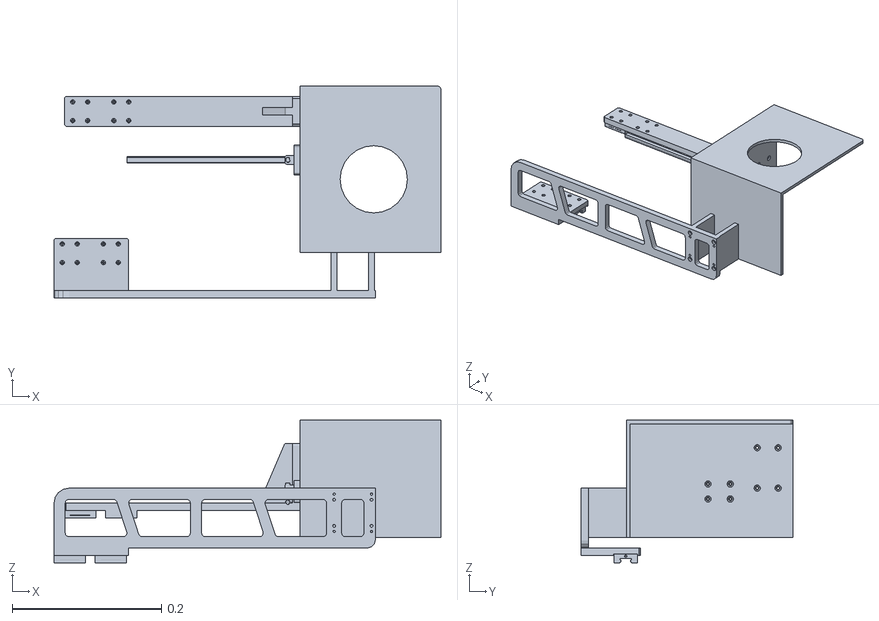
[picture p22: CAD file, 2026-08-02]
szlab_poly_studio/devices/szlab_mixer_pipetting_station/models/meshes/balance_door.stl
0.518 x 0.284 x 0.191

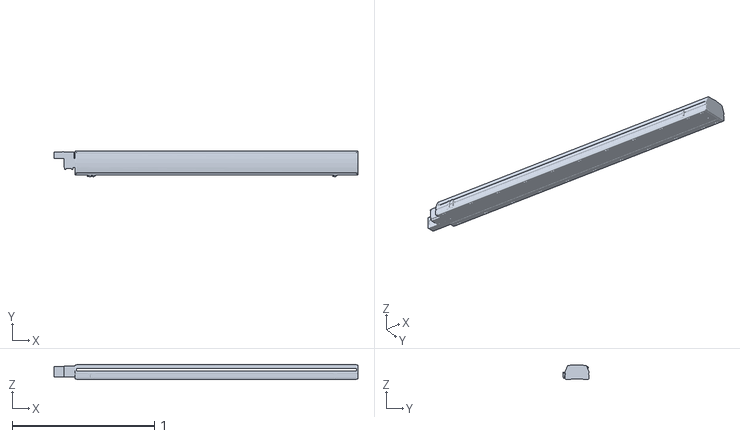
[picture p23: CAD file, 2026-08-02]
szlab_poly_studio/devices/szlab_mixer_robot/models/meshes/arm_slideway.stl
2.14 x 0.184 x 0.103

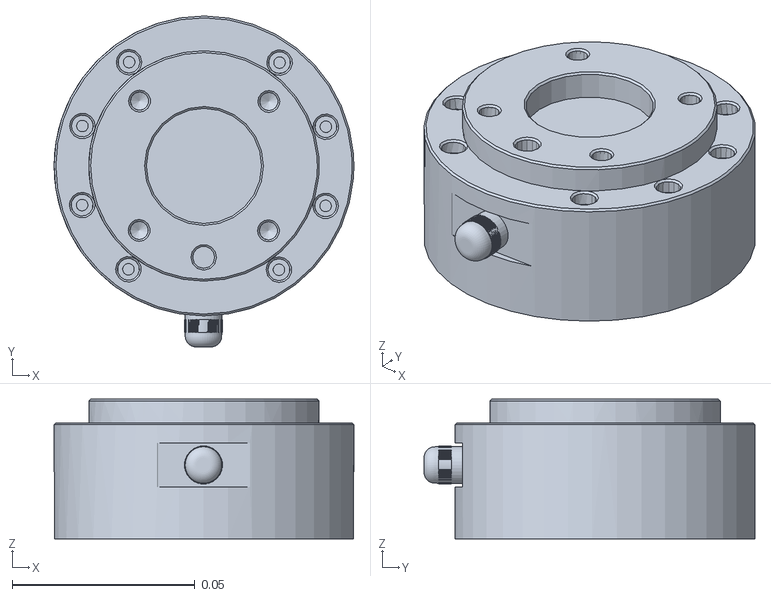
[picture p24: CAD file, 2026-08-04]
szlab_poly_studio/devices/szlab_mixer_robot/models/meshes/cr7/J6.STL
0.082 x 0.0905 x 0.0382

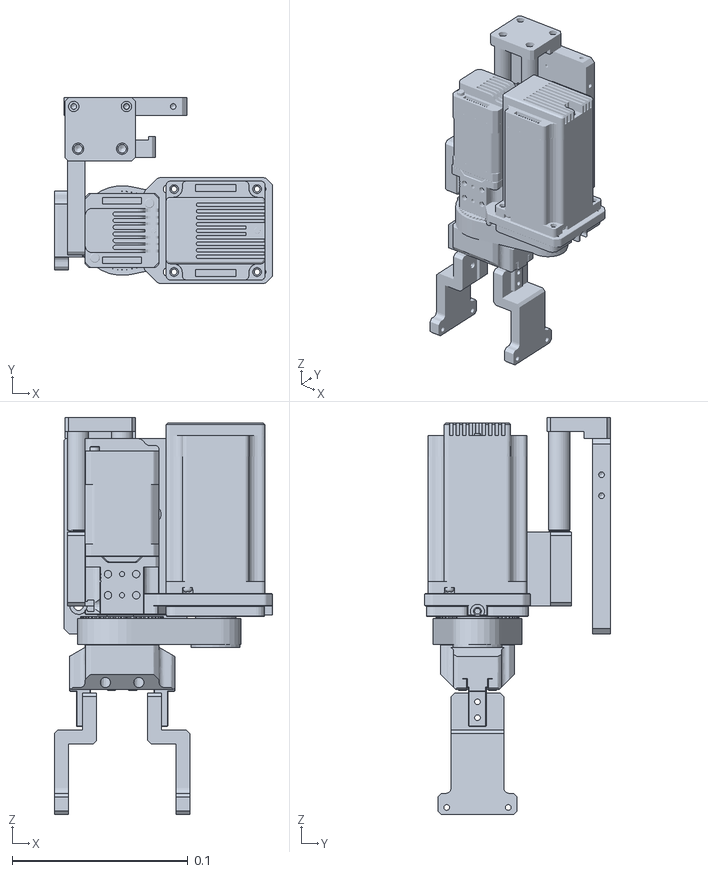
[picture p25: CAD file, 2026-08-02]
szlab_poly_studio/devices/szlab_s08_cap_station/models/meshes/move2_link.stl
0.124 x 0.106 x 0.226

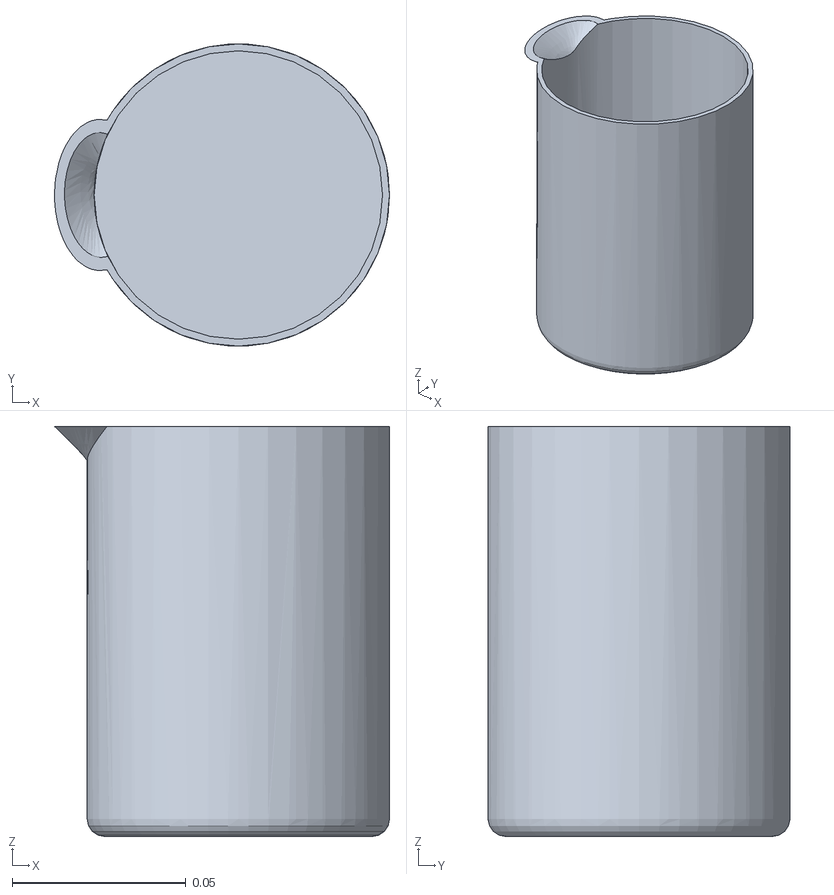
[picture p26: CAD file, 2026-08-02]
szlab_poly_studio/resources/szlab_beaker_500ml/models/meshes/base_link.stl
0.0964 x 0.087 x 0.118

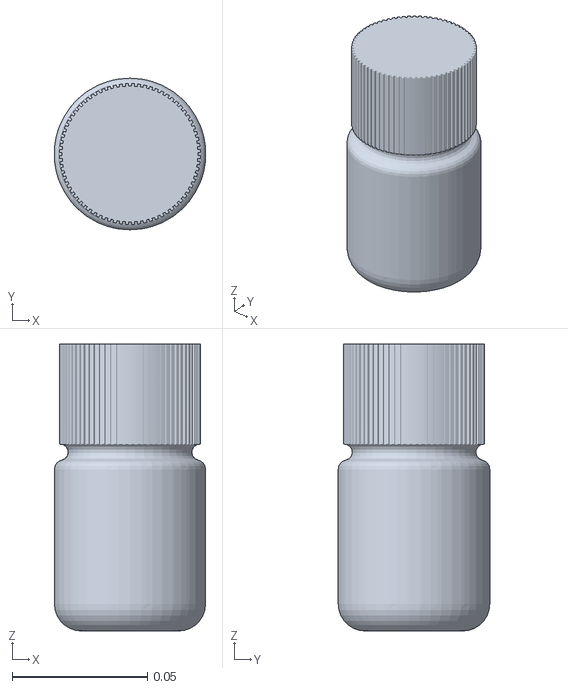
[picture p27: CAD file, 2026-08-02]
szlab_poly_studio/resources/szlab_liquid_reagent_bottle_100ml/models/meshes/base_link.stl
0.0558 x 0.056 x 0.106

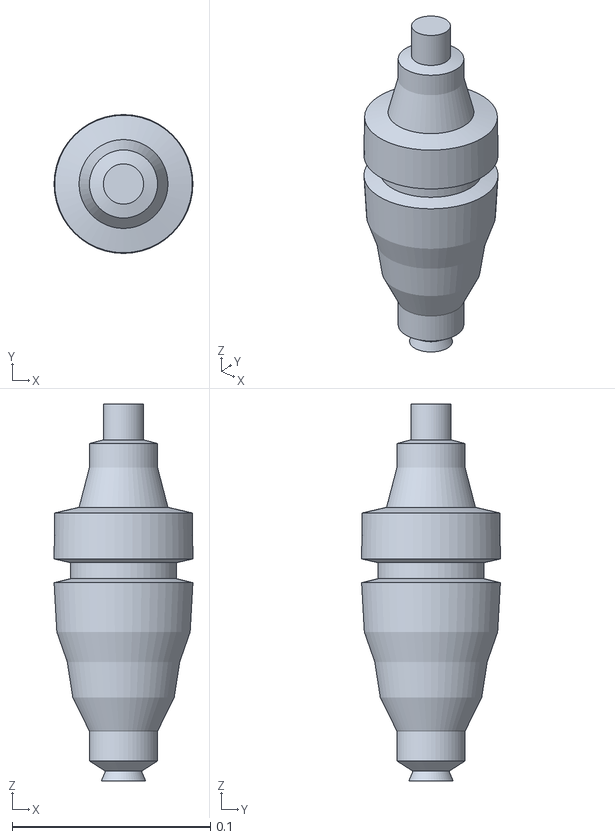
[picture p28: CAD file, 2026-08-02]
szlab_poly_studio/resources/szlab_powder_container/models/meshes/base_link.stl
0.07 x 0.07 x 0.19

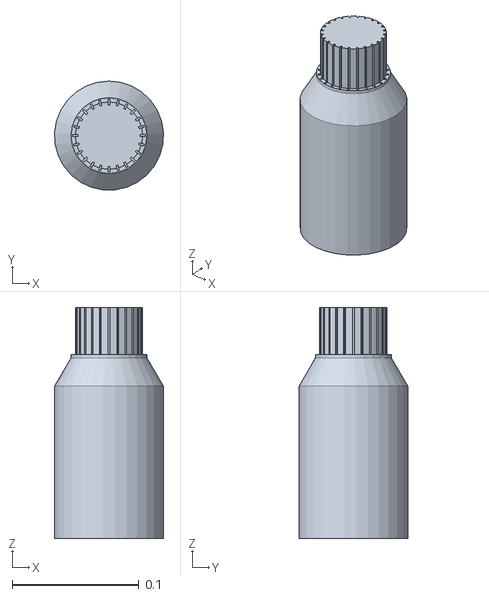
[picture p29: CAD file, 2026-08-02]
szlab_poly_studio/resources/szlab_sample_vial_500ml/models/meshes/base_link.stl
0.0859 x 0.0857 x 0.182

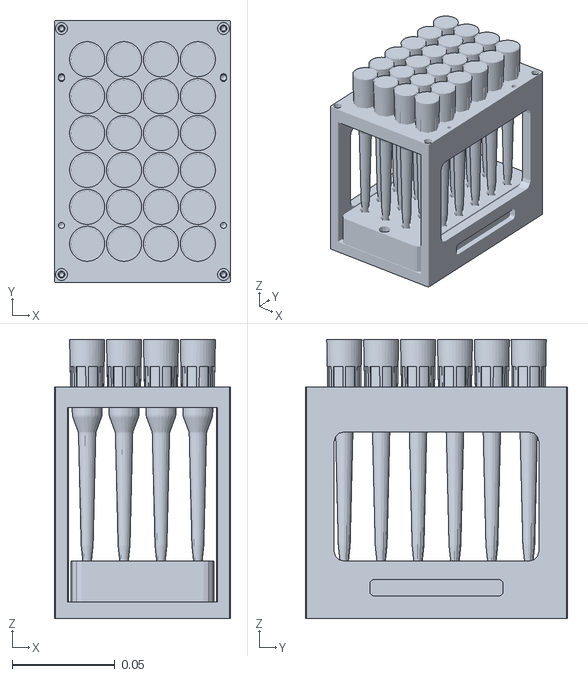
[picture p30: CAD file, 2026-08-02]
szlab_poly_studio/resources/szlab_tip_box/models/meshes/base_link.stl
0.086 x 0.128 x 0.136

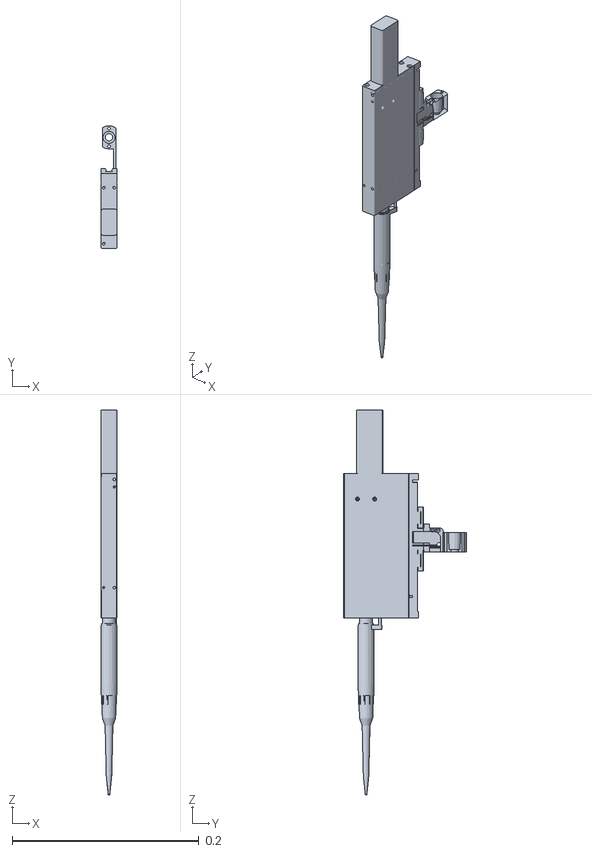
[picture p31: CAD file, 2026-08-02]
szlab_poly_studio/devices/szlab_mixer_pipetting_station/models/meshes/mz_link.stl
0.0171 x 0.131 x 0.413

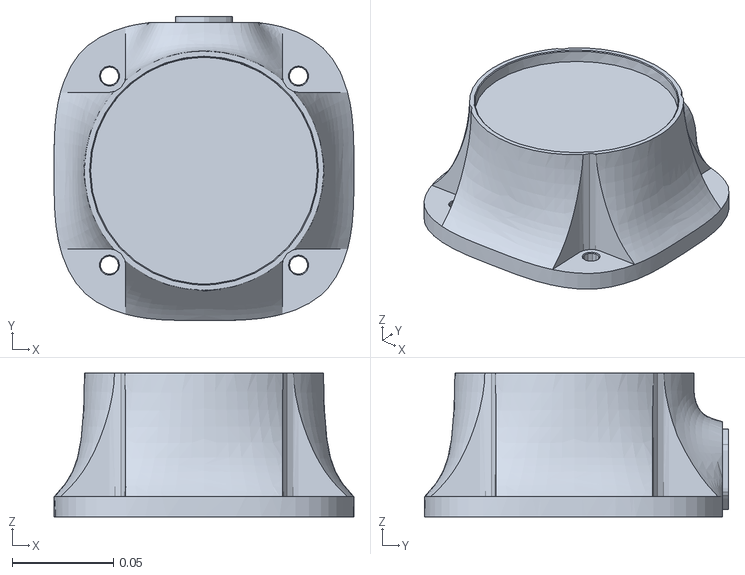
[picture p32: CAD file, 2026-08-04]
szlab_poly_studio/devices/szlab_mixer_robot/models/meshes/cr7/base_link0.STL
0.148 x 0.15 x 0.071

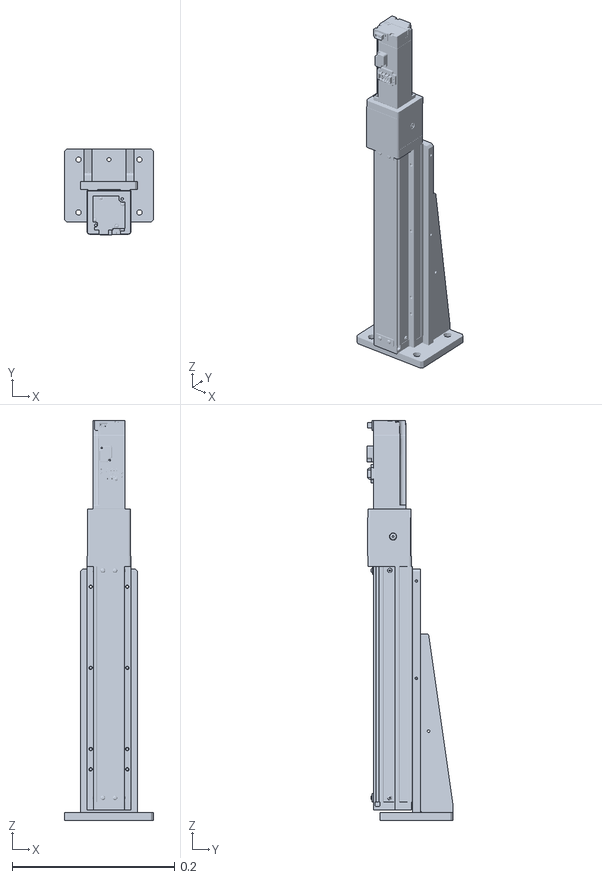
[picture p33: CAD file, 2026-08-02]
szlab_poly_studio/devices/szlab_s08_cap_station/models/meshes/move1_link.stl
0.11 x 0.106 x 0.493

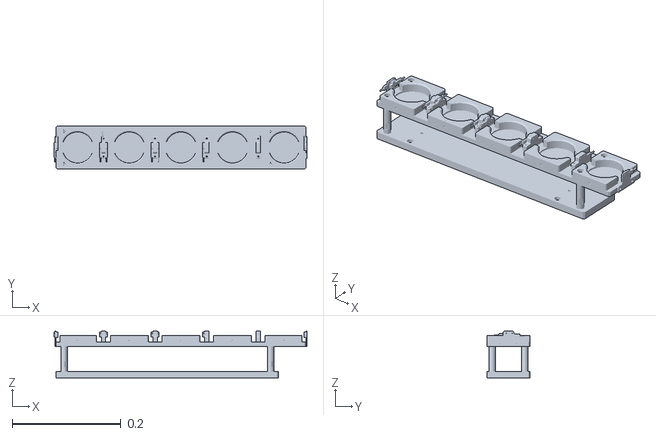
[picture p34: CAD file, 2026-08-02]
szlab_poly_studio/devices/szlab_mixer_pipetting_station/models/meshes/reagent_platform.stl
0.466 x 0.08 x 0.086

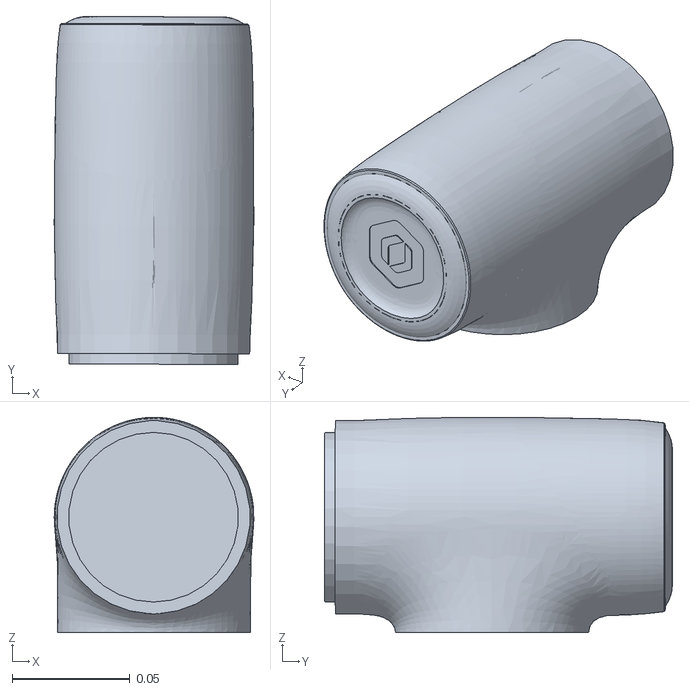
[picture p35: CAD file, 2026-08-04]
szlab_poly_studio/devices/szlab_mixer_robot/models/meshes/cr7/J4.STL
0.0847 x 0.148 x 0.0914

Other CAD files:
szlab_poly_studio/devices/szlab_mixer_pipetting_station/models/meshes/my_link.stl
szlab_poly_studio/devices/szlab_mixer_robot/models/meshes/cr7/J2.STL
szlab_poly_studio/devices/szlab_mixer_robot/models/meshes/cr7/J5.STL
szlab_poly_studio/devices/szlab_mixer_robot/models/meshes/cr7/J1.STL
szlab_poly_studio/devices/szlab_mixer_robot/models/meshes/cr7/J3.STL

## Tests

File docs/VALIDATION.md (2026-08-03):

# SZLab 根单包迁移验证

## 环境

在可导入相邻 `../Uni-Lab-OS` 的 Python 3.11 环境中执行。该 OS 必须包含 A1 typed
Action contract、`unilabos.registry.annotations` 和 I1 Workflow input/output integration：

```bash
export PYTHONPATH="../Uni-Lab-OS:$(pwd)${PYTHONPATH:+:${PYTHONPATH}}"
python -m pytest
./scripts/check-package.sh
./scripts/build-package.sh
```

## 验证范围

自动测试覆盖：

- 仓库不存在 `packages/` 层，distribution/import package 身份对齐；
- Catalog 发现 9 个 SZLab 设备和 14 个 SZLab 资源；
- 两个部署 Graph 的全部 class 都使用 `community.szlab_poly_studio.*` 并解析到 Catalog；
- 连接参数与物料拓扑只存在于 Graph，仓库不包含运行时 Profile；
- 13 个生产 Python 工作流可进入 Package Catalog，其中 S06 材料参考链验证 Action 级
  `ResourceSlot`、模板限制、命名 output 与线性绑定；
- 所有 decorator-bound `models/shape.yml` 路径存在且位于包内；
- 拆分后的外形仍覆盖设备、warehouse 和物料 category；
- Graph 中只有主 PLC 拥有直连配置，业务设备通过 `plc_device_id` 复用它；
- wheel 包含 CSV、JSON、工作流和模型 YAML，并嵌入 canonical Catalog；
- 未改变启动脚本的 755 权限。

## 后续模型验收

当前 Catalog、`--workspace`、clean-wheel parity 与 Shape 资产读取已覆盖。第一套真实 Xacro
进入仓库后，仍需补充 Web、kinematics、collision 与 `mesh_path` 的实物模型闭环。

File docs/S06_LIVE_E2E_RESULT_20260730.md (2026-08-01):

# S06 Robot 工作流真实 OPC UA 联调结果

## 结论

- 运行时间：2026-07-30 18:45（Asia/Shanghai）
- 工作流：`s06_robot_workflow`
- Run ID：`cbace3de8a584aab82c39c952c449179`
- OPC UA：`opc.tcp://opcua.ideawit.com:4855/xuse_sim`
- 工作流结构：3 节点、2 条控制边
- 最终状态：`completed`
- 节点结果：3/3 `success`
- 前端 API：30 次请求，HTTP 失败 0
- 浏览器错误：0

## 运行过程

| 时间 | 动作 | 握手结果 |
| --- | --- | --- |
| 18:45:16 | `submit_place_to_s06`，任务号 11 | accepted |
| 18:45:20 | S06 放料完成 | 烧杯传感器置 True，完成码 11 |
| 18:45:25 | 任务 11 复位 | 写入完成 False、任务号 0、完成码 0 |
| 18:45:32 | `run_solvent_addition`，工艺 1 | accepted |
| 18:45:33 | 泵 1 加液完成 | `S06_1号溶液添加量=8`，加工完成 True |
| 18:45:35 | S06 加液复位 | 工艺号 0、参数写入完成 False、加工完成 False |
| 18:45:41 | `submit_pick_from_s06`，任务号 12 | accepted |
| 18:45:45 | S06 取料完成 | 烧杯传感器置 False，完成码 12 |
| 18:45:50 | 任务 12 复位 | 写入完成 False、任务号 0、完成码 0 |

过程截图显示第一个节点成功、其余节点等待：

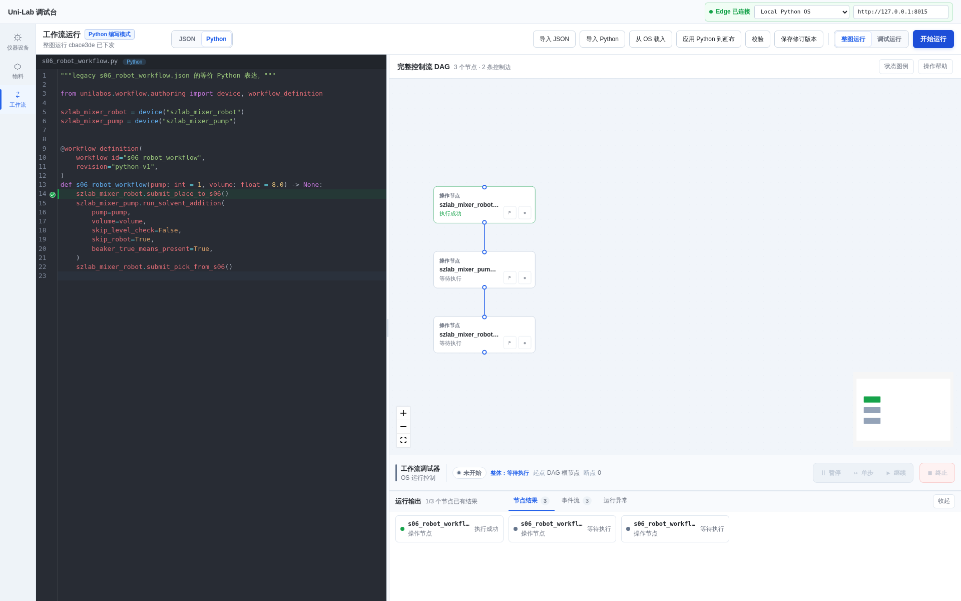
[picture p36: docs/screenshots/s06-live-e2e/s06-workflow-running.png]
S06 工作流运行过程


完成截图显示三个节点全部执行成功：

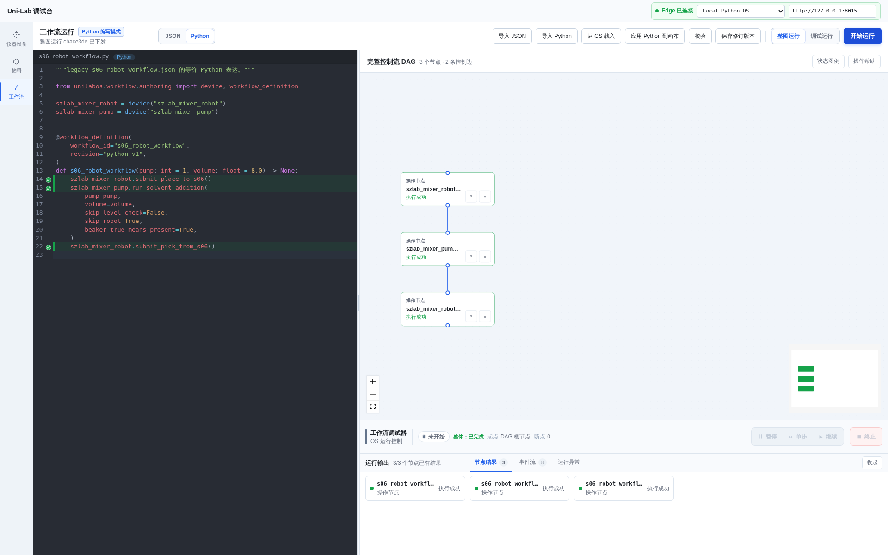
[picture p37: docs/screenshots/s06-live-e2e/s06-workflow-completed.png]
S06 工作流完成结果


事件流截图：

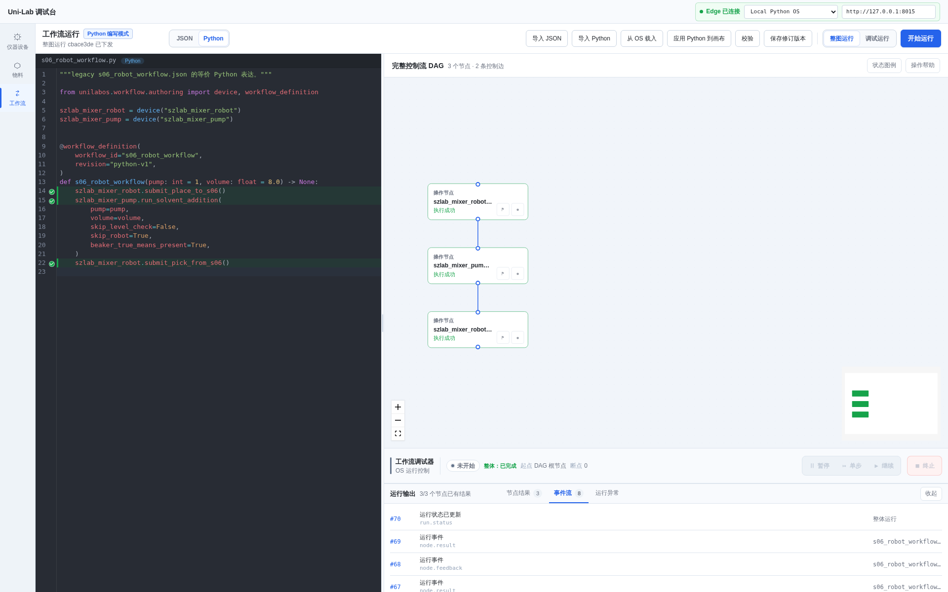
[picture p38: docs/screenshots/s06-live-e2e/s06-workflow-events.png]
S06 工作流事件流


## 结果文件

- `screenshots/s06-live-e2e/result-summary.json`：结果摘要
- `screenshots/s06-live-e2e/compiled-workflow.json`：由 `s06_robot.py` 编译出的工作流
- `screenshots/s06-live-e2e/run-created.json`：Run 创建响应
- `screenshots/s06-live-e2e/run-progress.json`：运行中状态、节点和事件
- `screenshots/s06-live-e2e/run-final.json`：最终状态、三个节点返回值和完整事件
- `screenshots/s06-live-e2e/run-timeline.json`：运行时间线投影
- `screenshots/s06-live-e2e/browser-api-calls.json`：前端 API 请求及浏览器错误
- `../runtime/s06-live-e2e/handshake.log`：握手器初始化、accepted/completed/reset 全过程
- `../runtime/s06-live-e2e/capture.log`：自动化采集结果
- `../runtime/ideawit-e2e/logs/ws_comm_2026-07-30 18-41-11.log`：Edge 收发 DAG、逐节点状态和 Run 终态

## 已知显示行为

运行过程截图中，第一节点已经成功时，底部整体状态仍可能短暂显示“等待执行”。
这是 Edge 只在设备反馈/终态时回传节点状态、动作等待 OPC 握手期间没有独立
`running` feedback 导致的显示滞后；本次三个设备终态和整个 Run 终态均已正常收敛。

Edge 启动阶段出现的云端 401 和 PLR Deck 序列化警告没有阻塞本次本地
Bridge/Edge/OPC UA 工作流执行。

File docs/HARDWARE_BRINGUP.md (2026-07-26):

# 真机接入清单

仓库默认配置只用于离线/测试模式。真机启用必须在受控网络中逐项完成：

1. 为每个 PLC/工站建立不入库的部署覆盖文件，填写 IP、端口、NodeId 映射和凭据。
2. 用只读连接验证 CSV 中全部节点类型、访问级别和 PLC 时钟；禁止先写变量再排查映射。
3. 分别验证工位 ready、home、allow-process、params-written、complete 和 reset 握手。
4. 校准 S01-S11 机械臂产品类型、位置编码、传感器前置条件和抓放完成后的物料状态。
5. 核对 S03/S11 堆栈、S2 枪头、S7 粉罐和 S10 液体试剂 warehouse 的现场位置与容量。
6. 验证 timeout、cancel、disconnect、急停与重启后的 reconcile 流程。
7. 先在 `--test_mode` 运行 Python 工作流，再按单工位、跨工位、整流程顺序解除模拟。
8. 保存经审核的运行日志、PLC 变量快照和物料快照，并由设备负责人批准生产切换。

不得把密码、token、可公网访问的 PLC 地址或跳过联锁的环境变量提交到仓库。

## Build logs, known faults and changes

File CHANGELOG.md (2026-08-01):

# Changelog

## Unreleased

- Converted the repository to one root distribution and one `szlab_poly_studio` import package.
- Moved device drivers under `devices/<device_id>/` and split AI4C into its own sibling repository.
- Bound model/shape assets directly to device and resource decorators.
- Removed the package-wide model provider and duplicate root Profile/spec copies.

## 0.1.0 - 2026-07-26

- Extracted SZLab polymer studio and AI4C drivers from the pinned `styx/dev` source.
- Added template v2 device specs, Profile v1 packages, 8 warehouses, 6 material types and a deck.
- Migrated 12 local UI presets and 6 legacy JSON workflows into 13 Python AST workflows.
- Added safe local deployment, latest frontend bridge startup, schema/registry/workflow tests and CI.

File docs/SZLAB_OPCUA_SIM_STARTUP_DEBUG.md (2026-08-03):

# SZLab FE-OS Workspace 启动与 OPC UA 仿真排障

本文档适用于完成 WorkflowTask/FE-OS migration 的 Uni-Lab-OS。领域仓库以
`--workspace` 显式挂载；一个 OS 进程同时提供设备运行、Workflow Authoring API 和 Web API。

## 1. 权威边界

- `pyproject.toml` 定义 distribution、import package 与运行依赖。
- `package.yaml` 只登记稳定 Workflow UUID 与源码位置。
- PackageCatalog 通过 AST 发现设备、资源、Workflow 和模型资产，不执行领域模块。
- Graph 是设备/物料实例、拓扑、连接参数和本次激活选择的唯一权威来源。
- `runtime/`、`unilabos_data/` 与 Workflow 数据库都是本地运行产物，不进入 wheel。

启动链路如下：

```text
Uni-Lab-SZLab workspace
  ├─ pyproject.toml + package.yaml + decorators ──> PackageCatalog
  └─ deployment/graphs/*.json ───────────────────> selected instances/config
                                                        │
                                                        v
                                              one Uni-Lab-OS process
                                              ├─ FE authoring API
                                              ├─ runtime API
                                              └─ device/resource runtime
```

## 2. 环境

```bash
cd /home/changjunhan/Uni-Lab-Core/Uni-Lab-SZLab

export UNILAB_OS_ROOT=/home/changjunhan/Uni-Lab-Core/.worktrees/uni-lab-os-f006-package-catalog
export UNILAB_PYTHON=/home/changjunhan/.micromamba/envs/unilab/bin/python
export PYTHONPATH="${UNILAB_OS_ROOT}:$(pwd)${PYTHONPATH:+:${PYTHONPATH}}"
```

合并后可将 `UNILAB_OS_ROOT` 改回正式的 `Uni-Lab-OS` checkout。

先验证 workspace：

```bash
"${UNILAB_PYTHON}" -m unilabos.app.main package inspect --path "$(pwd)"
"${UNILAB_PYTHON}" -m pytest
```

预期 Catalog 包含 9 个设备、14 个资源、12 个 Workflow 和 12 个模型资产。

## 3. 单设备调试

从完整 Graph 复制一个待调试设备节点及其必要物料节点到新的 JSON。Catalog 仍会发现整个领域包，
但只有 Graph 中选中的实例会被创建；连接参数继续写在节点的 `config` 中。

例如只调试 PLC 时，应至少保留：

```json
{
  "id": "szlab_poly_plc",
  "type": "device",
  "class": "community.szlab_poly_studio.szlab_poly_plc",
  "config": {
    "url": "opc.tcp://127.0.0.1:50100/",
    "csv_path": "szlab_plc_0730.csv",
    "auto_connect": false,
    "opcua_node_id_prefix": "ns=4;s=上位机通讯|",
    "connection_check_interval": 5.0,
    "reconnect_attempts": 3,
    "reconnect_delay": 1.0
  }
}
```

启动命令：

```bash
"${UNILAB_PYTHON}" -m unilabos.app.main \
  --workspace "$(pwd)" \
  --graph /absolute/path/to/single-device.json \
  --config "$(pwd)/deployment/local_config.py" \
  --working_dir "$(pwd)/runtime/single-device" \
  --backend ros \
  --app_bridges fastapi \
  --port 18003 \
  --disable_browser \
  --skip_env_check
```

首次接真机前先保持 `auto_connect: false`，核验 URL、NodeId、账号、联锁、急停和恢复语义后再启用。
`auto_connect: true` 时，主 PLC 驱动会定时读取 OPC UA `ServerStatus.State`；探测失败
或业务 I/O 遇到超时、socket 断开、无效 Session/SecureChannel 时，它会在同一 I/O 锁内
关闭旧会话、有限重连并重试原读写。`connection_check_interval: 0` 只关闭后台探测，
不关闭业务 I/O 的断线恢复。

## 4. 全工作区离线调试

`start-authoring-os.sh` 使用完整本地图、`simple` backend 和 `--test_mode`，适合调试 FE、
Workflow 编译、Graph 与物料展示：

```bash
UNILAB_OS_ROOT="${UNILAB_OS_ROOT}" \
UNILAB_PYTHON="${UNILAB_PYTHON}" \
  ./scripts/start-authoring-os.sh
```

默认 API 地址为 `http://127.0.0.1:8014`。前端可通过自己的本地 OS 地址参数连接该端口。

## 5. OPC UA 仿真与完整 Runtime

先启动 OPC UA server/握手器，再启动 OS：

```bash
UNILAB_OS_ROOT="${UNILAB_OS_ROOT}" \
UNILAB_PYTHON="${UNILAB_PYTHON}" \
UNILAB_SZLAB_GRAPH="$(pwd)/deployment/graphs/szlab-ideawit-sim.json" \
  ./scripts/start-runtime-os.sh
```

只验证运行链路、不下发真实硬件动作时增加：

```bash
UNILAB_TEST_MODE=1 ./scripts/start-runtime-os.sh
```

默认 OS API 地址为 `http://127.0.0.1:18003`。Workflow Authoring 与 Runtime 使用该进程内的
同一 TemplateCatalog 和 WorkflowStore，不需要额外的调度中转进程。

### 机器人加液与磁搅五节点 demo

`szlab_poly_studio/workflows/robot_liquid_stirring_demo.py` 依次执行 S06 放料、加液、
S06 取料、S04 放料和磁搅。启动对应握手场景：

```bash
"${UNILAB_PYTHON}" -u scripts/szlab_workflow_handshake.py serve \
  --workflow szlab_robot_liquid_stirring_demo_workflow \
  --url 'opc.tcp://opcua.ideawit.com:4855/xuse_sim' \
  --node-prefix 'ns=4;s=上位机通讯|' \
  --pump 1 \
  --process-delay 5.0 \
  --poll-interval 0.1 \
  --max-actions 5
```

该 demo 是现场握手联调源码；只有在 `package.yaml` 登记稳定 UUID 并升级到当前
decorator 合同后，才能当作持久 Package Workflow 发布。

## 6. 后台启动

```bash
mkdir -p runtime/ideawit-e2e/logs

nohup env \
  UNILAB_OS_ROOT="${UNILAB_OS_ROOT}" \
  UNILAB_PYTHON="${UNILAB_PYTHON}" \
  UNILAB_SZLAB_GRAPH="$(pwd)/deployment/graphs/szlab-ideawit-sim.json" \
  ./scripts/start-runtime-os.sh \
  > runtime/ideawit-e2e/logs/os.log 2>&1 &

printf '%s\n' "$!" > runtime/ideawit-e2e/os.pid
tail -f runtime/ideawit-e2e/logs/os.log
```

停止：

```bash
kill -TERM "$(sed -n '1p' runtime/ideawit-e2e/os.pid)"
```

## 7. 常见问题

### Catalog 编译失败

运行 `package inspect`，按结构化 diagnostic 修复。常见原因是：

- distribution 名归一化后与 import package 不一致；
- `package.yaml` 的 UUID 或源码路径与 decorator 不一致；
- decorator 使用动态 ID 或动态模型路径；
- wheel 未包含 Catalog closure 中的源码/资产。

### Workflow 未被发现

确认 `package.yaml` 已登记对应 UUID，源码位于
`szlab_poly_studio/workflows/<name>.py`，且 `@workflow_definition.workflow_uuid`
完全相同。仅放置一个带 decorator 的 Python 文件不会自动成为持久 Workflow source。

### Workflow 编译提示 selector 无效

设备选择器必须是模块级、有绝对导入类型注解的赋值：

```python
from szlab_poly_studio.devices.szlab_mixer_pump.device import SzlabMixerPumpDevice
from unilabos.workflow.authoring import device

szlab_mixer_pump: SzlabMixerPumpDevice = device("szlab_mixer_pump")
```

Workflow 参数必须是 keyword-only；每个 action result 必须绑定到唯一名字，并使用稳定的
`# unilab:node_uuid=...` anchor。

### Graph class 不存在

Graph 中的 `class` 必须使用 Catalog FQID，例如
`community.szlab_poly_studio.szlab_mixer_pump`，不能使用旧的非命名空间 ID。

### 连接失败

优先检查 Graph 节点 `config`，再检查网络与 OPC UA server。不要把 URL、串口、账号或连接开关
移回 Python 默认值、Profile 或额外启动配置。

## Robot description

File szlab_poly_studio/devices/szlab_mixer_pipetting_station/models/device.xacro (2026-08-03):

<?xml version="1.0" encoding="utf-8"?>
<robot xmlns:xacro="http://www.ros.org/wiki/xacro">
  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
  <xacro:macro name="szlab_mixer_pipetting_station" params="parent_link:='' station_name:='' device_name:='' x:=0 y:=0 z:=0 rx:=0 ry:=0 r:=0 mesh_path:=''">
    <joint name="${station_name}${device_name}base_link_joint" type="fixed">
      <origin xyz="${x} ${y} ${z}" rpy="${rx} ${ry} ${r}"/>
      <parent link="${parent_link}"/>
      <child link="${station_name}${device_name}device_link"/>
      <axis xyz="0 0 0"/>
    </joint>
    <link name="${station_name}${device_name}device_link"/>
    <joint name="${station_name}${device_name}device_link_joint" type="fixed">
      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
      <origin xyz="0.0585 0.033 0" rpy="0 0 0"/>
      <parent link="${station_name}${device_name}device_link"/>
      <child link="${station_name}${device_name}base_link"/>
      <axis xyz="0 0 0"/>
    </joint>

    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
    <link name="${station_name}${device_name}base_link">
      <inertial>
        <origin xyz="0.4 0.235 0.006" rpy="0 0 0"/>
        <mass value="20.0"/>
        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
      </inertial>
      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
    </link>

    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
    <joint name="${station_name}${device_name}pipetting_station_joint" type="fixed">
      <origin xyz="0.2615 0.429 0.012" rpy="0 0 0"/>
      <parent link="${station_name}${device_name}base_link"/>
      <child link="${station_name}${device_name}pipetting_station"/>
      <axis xyz="0 0 0"/>
    </joint>
    <link name="${station_name}${device_name}pipetting_station">
      <inertial>
        <origin xyz="0.0197060862260998 0.0190352862014106 0.297332736876544" rpy="0 0 0"/>
        <mass value="9.62327791097001"/>
        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
      </inertial>
      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
    </link>

    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
    <link name="${station_name}${device_name}mx_link">
      <inertial>
        <origin xyz="-0.0261820136431608 -0.129016031135948 0.0773928355405431" rpy="0 0 0"/>
        <mass value="2.40311603103846"/>
        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
      </inertial>
      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
    </link>
    <link name="${station_name}${device_name}my_link">
      <inertial>
        <origin xyz="0.00966989436612542 0.015223001194224 -0.000920195330581686" rpy="0 0 0"/>
        <mass value="0.81249207130995"/>
        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
      </inertial>
      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
    </link>
    <link name="${station_name}${device_name}mz_link">
      <inertial>
        <origin xyz="0.000301508907735393 -0.054995 -0.16201064591941" rpy="0 0 0"/>
        <mass value="0.0270765241188538"/>
        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
      </inertial>
      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
    </link>
    <joint name="${station_name}${device_name}mx_joint" type="prismatic">
      <origin xyz="-0.20902 0 0.405" rpy="0 0 0"/>
      <parent link="${station_name}${device_name}pipetting_station"/>
      <child link="${station_name}${device_name}mx_link"/>
      <axis xyz="1 0 0"/>
      <limit lower="0" upper="0.54" effort="0" velocity="0"/>
    </joint>
    <joint name="${station_name}${device_name}my_joint" type="prismatic">
      <origin xyz="0.039017 -0.356 0.068" rpy="0 0 0"/>
      <parent link="${station_name}${device_name}mx_link"/>
      <child link="${station_name}${device_name}my_link"/>
      <axis xyz="0 1 0"/>
      <limit lower="0" upper="0.25" effort="0" velocity="0"/>
    </joint>
    <joint name="${station_name}${device_name}mz_joint" type="prismatic">
      <origin xyz="0.032198 -0.027 0.036305" rpy="0 0 0"/>
      <parent link="${station_name}${device_name}my_link"/>
      <child link="${station_name}${device_name}mz_link"/>
      <axis xyz="0 0 -1"/>
      <limit lower="0" upper="0.18" effort="0" velocity="0"/>
    </joint>

    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
    <joint name="${station_name}${device_name}tip_platform_joint" type="fixed">
      <origin xyz="0.230279 0.168125 0.012" rpy="0 0 0"/>
      <parent link="${station_name}${device_name}base_link"/>
      <child link="${station_name}${device_name}tip_platform"/>
      <axis xyz="0 0 0"/>
    </joint>
    <link name="${station_name}${device_name}tip_platform">
      <inertial>
        <origin xyz="-0.000347088367277444 -9.71045386745258E-05 0.107097368994441" rpy="0 0 0"/>
        <mass value="4.63852389146957"/>
        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
      </inertial>
      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
    </link>

    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
    <joint name="${station_name}${device_name}reagent_platform_joint" type="fixed">
      <origin xyz="0.301612 0.04 0.012" rpy="0 0 0"/>
      <parent link="${station_name}${device_name}base_link"/>
      <child link="${station_name}${device_name}reagent_platform"/>
      <axis xyz="0 0 0"/>
    </joint>
    <link name="${station_name}${device_name}reagent_platform">
      <inertial>
        <origin xyz="0.0132681341208297 1.85704936205289E-05 0.0378724241274126" rpy="0 0 0"/>
        <mass value="2.3172510944123"/>
        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
      </inertial>
      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
    </link>

    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
    <joint name="${station_name}${device_name}balance_shield_joint" type="fixed">
      <origin xyz="0.4085 0.2235 0.012" rpy="0 0 0"/>
      <parent link="${station_name}${device_name}base_link"/>
      <child link="${station_name}${device_name}balance_shield"/>
      <axis xyz="0 0 0"/>
    </joint>
    <link name="${station_name}${device_name}balance_shield">
      <inertial>
        <origin xyz="-0.108919629585566 0.0679356981259998 0.0610381696743503" rpy="0 0 0"/>
        <mass value="3.99604616856123"/>
        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
      </inertial>
      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
    </link>
    <link name="${station_name}${device_name}balance_door">
      <inertial>
        <origin xyz="0.391472461601486 -0.0689929195735358 -0.000484426777066227" rpy="0 0 0"/>
        <mass value="1.92095332718505"/>
        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
      </inertial>
      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
    </link>
    <joint name="${station_name}${device_name}balance_door_joint" type="prismatic">
      <origin xyz="-0.29587 0.045148 0.13" rpy="0 0 0"/>
      <parent link="${station_name}${device_name}balance_shield"/>
      <child link="${station_name}${device_name}balance_door"/>
      <axis xyz="-1 0 0"/>
      <limit lower="0" upper="0.2" effort="0" velocity="0"/>
    </joint>
  </xacro:macro>
</robot>

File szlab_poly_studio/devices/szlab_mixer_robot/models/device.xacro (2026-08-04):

<?xml version="1.0" ?>
<robot xmlns:xacro="http://www.ros.org/wiki/xacro" name="szlab_mixer_robot">

  <xacro:macro name="szlab_mixer_robot" params="parent_link:='' station_name:='' device_name:='' x:=0 y:=0 z:=0 rx:=0 ry:=0 r:=0 mesh_path:=''">
    <xacro:property name="joint_limit_parameters" value="${xacro.load_yaml(mesh_path + '/joint_limit.yaml')}"/>
    <xacro:property name="sec_limits" value="${joint_limit_parameters['joint_limits']}"/>
    <xacro:property name="limit_arm_base_joint" value="${sec_limits['arm_base_joint']}"/>
    <xacro:property name="limit_cr7_joint_1" value="${sec_limits['cr7_joint_1']}"/>
    <xacro:property name="limit_cr7_joint_2" value="${sec_limits['cr7_joint_2']}"/>
    <xacro:property name="limit_cr7_joint_3" value="${sec_limits['cr7_joint_3']}"/>
    <xacro:property name="limit_cr7_joint_4" value="${sec_limits['cr7_joint_4']}"/>
    <xacro:property name="limit_cr7_joint_5" value="${sec_limits['cr7_joint_5']}"/>
    <xacro:property name="limit_cr7_joint_6" value="${sec_limits['cr7_joint_6']}"/>

    <joint name="${station_name}${device_name}base_link_joint" type="fixed">
      <origin xyz="${x} ${y} ${z}" rpy="${rx} ${ry} ${r}"/>
      <parent link="${parent_link}"/>
      <child link="${station_name}${device_name}device_link"/>
      <axis xyz="0 0 0"/>
    </joint>

    <link name="${station_name}${device_name}device_link"/>
    <joint name="${station_name}${device_name}device_link_joint" type="fixed">
      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
      <origin xyz="0 0.08 0" rpy="0 0 0"/>
      <parent link="${station_name}${device_name}device_link"/>
      <child link="${station_name}${device_name}arm_slideway"/>
      <axis xyz="0 0 0"/>
    </joint>

    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
    <link name="${station_name}${device_name}arm_slideway">
      <inertial>
        <origin rpy="0 0 0" xyz="-1.3696833695310285 -0.00141851388483838 0.0416079172839272"/>
        <mass value="13.6578107753627"/>
        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
      </inertial>
      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
    </link>

    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
    <joint name="${station_name}${device_name}arm_base_joint" type="prismatic">
      <origin rpy="0 0 0" xyz="0.4605 0 0.1225"/>
      <parent link="${station_name}${device_name}arm_slideway"/>
      <child link="${station_name}${device_name}cr7_base"/>
      <axis xyz="1 0 0"/>
      <limit effort="${limit_arm_base_joint['effort']}" lower="${limit_arm_base_joint['lower']}" upper="${limit_arm_base_joint['upper']}" velocity="${limit_arm_base_joint['velocity']}"/>
    </joint>

    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
    <link name="${station_name}${device_name}cr7_base">
      <inertial>
        <origin xyz="-7.75881826404344E-06 0.00191109737802069 0.0289949710713939" rpy="0 0 0"/>
        <mass value="0.908795453638862"/>
        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
      </inertial>
      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
    </link>

    <link name="${station_name}${device_name}cr7_link_1">
      <inertial>
        <origin xyz="2.42083892138974E-07 -0.00325669708857515 -0.00767435596457115" rpy="0 0 0"/>
        <mass value="1.6123155679073"/>
        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
      </inertial>
      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
    </link>
    <joint name="${station_name}${device_name}cr7_joint_1" type="revolute">
      <origin xyz="0 0 0.147" rpy="0 0 0"/>
      <parent link="${station_name}${device_name}cr7_base"/>
      <child link="${station_name}${device_name}cr7_link_1"/>
      <axis xyz="0 0 1"/>
      <limit effort="${limit_cr7_joint_1['effort']}" lower="${limit_cr7_joint_1['lower']}" upper="${limit_cr7_joint_1['upper']}" velocity="${limit_cr7_joint_1['velocity']}"/>
    </joint>

    <link name="${station_name}${device_name}cr7_link_2">
      <inertial>
        <origin xyz="-0.188500103625708 -7.46110088887752E-07 0.142319304936727" rpy="0 0 0"/>
        <mass value="5.28764336862191"/>
        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
      </inertial>
      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
    </link>
    <joint name="${station_name}${device_name}cr7_joint_2" type="revolute">
      <origin xyz="0 0 0" rpy="-1.57080420997483 1.57079631189374 -3.14158502419526"/>
      <parent link="${station_name}${device_name}cr7_link_1"/>
      <child link="${station_name}${device_name}cr7_link_2"/>
      <axis xyz="0 0 1"/>
      <limit effort="${limit_cr7_joint_2['effort']}" lower="${limit_cr7_joint_2['lower']}" upper="${limit_cr7_joint_2['upper']}" velocity="${limit_cr7_joint_2['velocity']}"/>
    </joint>

    <link name="${station_name}${device_name}cr7_link_3">
      <inertial>
        <origin xyz="-0.129084033261017 0.000409825982416691 -0.0024891265183234" rpy="0 0 0"/>
        <mass value="2.64536322797469"/>
        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
      </inertial>
      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
    </link>
    <joint name="${station_name}${device_name}cr7_joint_3" type="revolute">
      <origin xyz="-0.377 0 0.025" rpy="0 0 0"/>
      <parent link="${station_name}${device_name}cr7_link_2"/>
      <child link="${station_name}${device_name}cr7_link_3"/>
      <axis xyz="0 0 1"/>
      <limit effort="${limit_cr7_joint_3['effort']}" lower="${limit_cr7_joint_3['lower']}" upper="${limit_cr7_joint_3['upper']}" velocity="${limit_cr7_joint_3['velocity']}"/>
    </joint>

    <link name="${station_name}${device_name}cr7_link_4">
      <inertial>
        <origin xyz="-0.00098049161725656 -0.00207570116557487 -0.00155508673006152" rpy="0 0 0"/>
        <mass value="0.670573134819647"/>
        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
      </inertial>
      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
    </link>
    <joint name="${station_name}${device_name}cr7_joint_4" type="revolute">
      <origin xyz="-0.306999999999969 0 0.116" rpy="0 0 -1.57079677671549"/>
      <parent link="${station_name}${device_name}cr7_link_3"/>
      <child link="${station_name}${device_name}cr7_link_4"/>
      <axis xyz="0 0 0.999999999969965"/>
      <limit effort="${limit_cr7_joint_4['effort']}" lower="${limit_cr7_joint_4['lower']}" upper="${limit_cr7_joint_4['upper']}" velocity="${limit_cr7_joint_4['velocity']}"/>
    </joint>
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

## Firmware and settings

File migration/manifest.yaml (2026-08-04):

schema_version: 1
source:
  repository: https://github.com/styxhuang/Uni-Lab-OS
  branch: dev
  commit: d58a8c0d6de26b9de77161359bb627d75fa8e4e8
template:
  repository: https://github.com/Uni-Lab-OS/Uni-Lab-Templates
  branch: main
  commit: 5e44020e1020577b0c00ba196f82a7e434983b29
integration_guide:
  url: https://dptechnology.feishu.cn/docx/YRZtdUKkJo1zu4xgjohcc498neh
  access: enterprise_login_required
  fallback: styx/dev .cursor/skills/add-device/SKILL.md self-contained rules plus current template schemas
capture:
  committed_presets: 11
  committed_legacy_workflows: 6
  live_browser_draft_found: false
  note: 定向检查当前调试目录和浏览器/e2e 持久化位置，未发现可归属到该项目的活动 localStorage 草稿。
action_reference_migration:
  legacy_rule: auto-<method>
  current_rule: <method>
  reason: Python AST 工作流通过 device("<device_id>").<method>(...) 表达，动作名必须是合法 Python 属性。

presets:
  - id: magnetic_stirring
    legacy_preset: legacy/ui-presets/magnetic_stirring.json
    legacy_runtime: legacy/runtime-configs/magnetic_stirring_runtime.json
    workflow_id: szlab_magnetic_stirring_workflow
    python_source: ../szlab_poly_studio/workflows/magnetic_stirring.py
    devices: [szlab_mixer_stirrer]
    equivalence: committed_preset
  - id: photoshotting
    legacy_preset: legacy/ui-presets/photoshotting.json
    legacy_runtime: legacy/runtime-configs/photoshotting_runtime.json
    workflow_id: szlab_photoshotting_workflow
    python_source: ../szlab_poly_studio/workflows/photoshotting.py
    devices: [szlab_mixer_photoshotting]
    equivalence: committed_preset
  - id: robot_action
    legacy_preset: legacy/ui-presets/robot_action.json
    legacy_runtime: legacy/runtime-configs/szlab_mixer_runtime.json
    workflow_id: szlab_robot_action_workflow
    python_source: ../szlab_poly_studio/workflows/robot_action.py
    devices: [szlab_mixer_robot]
    equivalence: committed_preset
  - id: s04_robot_stirring
    legacy_preset: legacy/ui-presets/s04_robot_stirring.json
    legacy_runtime: legacy/runtime-configs/s04_robot_stirring_runtime.json
    legacy_workflow: legacy/workflows/s04_robot_stirring_workflow.json
    workflow_id: s04_robot_stirring_workflow
    python_source: ../szlab_poly_studio/workflows/s04_robot_stirring.py
    devices: [szlab_mixer_robot, szlab_mixer_stirrer]
    equivalence: exact_action_sequence
  - id: s06_robot
    legacy_preset: legacy/ui-presets/s06_robot.json
    legacy_runtime: legacy/runtime-configs/s06_robot_runtime.json
    legacy_workflow: legacy/workflows/s06_robot_workflow.json
    workflow_id: s06_robot_workflow
    python_source: ../szlab_poly_studio/workflows/s06_robot.py
    devices: [szlab_mixer_robot, szlab_mixer_pump]
    equivalence: exact_action_sequence
  - id: s07_robot
    legacy_preset: legacy/ui-presets/s07_robot.json
    legacy_runtime: legacy/runtime-configs/s07_robot_runtime.json
    legacy_workflow: legacy/workflows/s07_robot_workflow.json
    workflow_id: s07_robot_workflow
    python_source: ../szlab_poly_studio/workflows/s07_robot.py
    devices: [szlab_mixer_robot]
    equivalence: exact_action_sequence
  - id: s08_cap_station
    legacy_preset: legacy/ui-presets/s08_cap_station.json
    legacy_runtime: legacy/runtime-configs/s08_cap_station_runtime.json
    legacy_workflow: legacy/workflows/s08_open_close_workflow.json
    workflow_id: s08_cap_workflow
    python_source: ../szlab_poly_studio/workflows/s08_cap.py
    devices: [szlab_s08_cap_station]
    equivalence: scalar_adapter_for_legacy_sample_id_list
  - id: s09_pipetting_station
    legacy_preset: legacy/ui-presets/s09_pipetting_station.json
    legacy_runtime: legacy/runtime-configs/s09_pipetting_station_runtime.json
    workflow_id: s09_移液调试
    python_source: ../szlab_poly_studio/workflows/s09_pipetting.py
    devices: [szlab_mixer_pipetting_station]
    equivalence: committed_preset
  - id: solid_addition_s07
    legacy_preset: legacy/ui-presets/solid_addition_s07.json
    legacy_runtime: legacy/runtime-configs/solid_addition_s07_runtime.json
    workflow_id: szlab_s07_solid_addition_workflow
    python_source: ../szlab_poly_studio/workflows/s07_solid_addition.py
    devices: [szlab_s07_solid_addition]
    equivalence: committed_preset
  - id: stack_s05_s06
    legacy_preset: legacy/ui-presets/stack_s05_s06.json
    legacy_runtime: legacy/runtime-configs/stack_s05_s06_runtime.json
    workflow_id: szlab_stack_s05_s06_workflow
    python_source: ../szlab_poly_studio/workflows/stack_s05_s06.py
    devices: [szlab_poly_plc, szlab_mixer_photoshotting, szlab_mixer_pump]
    equivalence: committed_preset
  - id: szlab_mixer
    legacy_preset: legacy/ui-presets/szlab_mixer.json
    legacy_runtime: legacy/runtime-configs/szlab_mixer_runtime.json
    legacy_workflow: legacy/workflows/szlab_mixer_workflow.json
    workflow_id: szlab_mixer_workflow
    python_source: ../szlab_poly_studio/workflows/szlab_mixer.py
    devices: [szlab_mixer_pump]
    equivalence: exact_action_sequence
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

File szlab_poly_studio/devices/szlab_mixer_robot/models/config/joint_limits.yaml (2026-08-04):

# joint_limits.yaml allows the dynamics properties specified in the URDF to be overwritten or augmented as needed

# For beginners, we downscale velocity and acceleration limits.
# You can always specify higher scaling factors (<= 1.0) in your motion requests.  # Increase the values below to 1.0 to always move at maximum speed.
default_velocity_scaling_factor: 0.1
default_acceleration_scaling_factor: 0.1

# Specific joint properties can be changed with the keys [max_position, min_position, max_velocity, max_acceleration]
# Joint limits can be turned off with [has_velocity_limits, has_acceleration_limits]
joint_limits:
  arm_base_joint:
    has_velocity_limits: true
    max_velocity: 0
    has_acceleration_limits: false
    max_acceleration: 0
  cr7_joint_1:
    has_velocity_limits: true
    max_velocity: 0
    has_acceleration_limits: false
    max_acceleration: 0
  cr7_joint_2:
    has_velocity_limits: true
    max_velocity: 0
    has_acceleration_limits: false
    max_acceleration: 0
  cr7_joint_3:
    has_velocity_limits: true
    max_velocity: 0
    has_acceleration_limits: false
    max_acceleration: 0
  cr7_joint_4:
    has_velocity_limits: true
    max_velocity: 0
    has_acceleration_limits: false
    max_acceleration: 0
  cr7_joint_5:
    has_velocity_limits: true
    max_velocity: 0
    has_acceleration_limits: false
    max_acceleration: 0
  cr7_joint_6:
    has_velocity_limits: true
    max_velocity: 0
    has_acceleration_limits: false
    max_acceleration: 0

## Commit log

2026-07-26 feat: add SZLab and AI4C Uni-Lab integration
    [ai4c_nodes.csv, ai4c_robot.yaml, ai4c_sim_updated_local.csv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]
2026-07-30 feat(szlab): add unified PLC workflow simulation
    [szlab_plc_0730.csv]
2026-07-30 添加部分说明文档
2026-07-30 修改桌面布局，并添加2.5d的物料与设备展示
2026-07-30 启动脚本
2026-07-31 feat(materials): publish SZLab 2.5D shapes
2026-08-01 refactor: migrate SZLab to root domain package
    Remove the packages layer and model bundle protocol, colocate device and resource models, move AI4C to its own repository boundary, and refresh validation/E2E evidence.\n\nRefs: https://github.com/Uni-Lab-OS/Uni-Lab-SZLab/issues/1
    [ai4c_nodes.csv, ai4c_robot.yaml, ai4c_sim_updated_local.csv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]
2026-08-02 添加szlab的3D模型
    [balance_door.stl, base_link.stl, device.xacro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]
2026-08-02 更新3D模型
    [arm_slideway.stl, base_link.stl, device.xacro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]
2026-08-02 feat: adopt material-aware SZLab workflows
2026-08-03 feat: register S07 material dosing workflow
2026-08-03 feat(workflow): validate S07 material robot execution
2026-08-03 test(models): require S07 material render assets
2026-08-03 test(models): pin S07 material placement origins
2026-08-03 fix(models): restore model-owned placement origins
    [device.xacro, resource.xacro]
2026-08-03 fix(models): align pre-oriented warehouse meshes
    [resource.xacro]
2026-08-04 feat(workflow): add material-aware SZLab workflows
2026-08-04 feat(devices): align SZLab drivers with assemble runtime
2026-08-04 feat(handshake): sync SZLab workflow simulator
    [s07_nodes.csv, szlab_plc_0730.csv]
2026-08-04 feat(plc): add SZLab 0731 variable table
    [szlab_plc_0731.csv]
2026-08-04 更新机械臂模型
    [J1.STL, J2.STL, J3.STL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]
2026-08-06 fix: 补全机器人取放料负载握手见证
2026-08-06 feat(workflow): run material-aware composite transfers
2026-08-07 Add PLC graph and update SZLab workflows
    Introduces a new `deployment/graphs/szlab-plc.json` topology and adds the new PLC register map `szlab_plc_0807.csv`. Updates local debug PLC config to connect to the real OPC UA endpoint with auto-co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
    Also updates workflow wiring: the single-sample material workflow now uses the new production source site UUID (with its test updated accordingly), and the S06 mixer workflow is renamed/refined with 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
    [szlab_plc_0807.csv]
2026-08-07 Add beaker transfer chain workflow support
    Introduce a new five-station beaker transfer workflow and register it in package metadata. Refactor S04 and S06 workflows to use standard pick/place + host material commit + material-aware device act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
2026-08-07 fix(workflow): support material sources in PLC-Sim graph
2026-08-07 fix(workflow): use S0722 in beaker transfer chain
